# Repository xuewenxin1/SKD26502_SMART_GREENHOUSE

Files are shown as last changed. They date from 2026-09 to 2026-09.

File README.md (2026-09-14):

# SKD26502 大棚智能温湿度计和放风机

> **最近改了什么、主要在哪个文件夹？** 请看 [`修改说明_README.md`](修改说明_README.md)。

| 按键 | 作用 |
|---|---|
| **F7** | 编译并烧录放风机（`04.controller_unit_motor_freertos`） |
| **F8** | 编译并烧录温湿度计（`04.controller_unit_sensor_freertos`） |
| 终端任务 `Build All` | 两个固件都编译 |

烧录用 `pyocd`（驱动 ST-Link），芯片 `py32f071xb`。请先接好调试器再按 F7 或 F8。

产物在各自工程的 `build` 目录：`SKD26502_SMART_GREENHOUSE.hex` / `.bin` / `.elf`。

**电脑什么都没装时（只烧录，不编译）：**  
打开文件夹 **`烧录包`**（可整夹拷走），看里面的 `使用说明.txt`：  
1）第一次双击 `setup_flash_env.bat`  
2）插 ST-Link、板子上电  
3）双击 `flash_motor.bat`（烧 `SKD26502_motor.bin`）或 `flash_sensor.bat`（烧 `SKD26502_sensor.bin`）  

重新编译后，在烧录包里运行 `sync_bins_from_build.bat` 可更新这两个 bin。

日常开发编译仍需要：CMake、Ninja、Arm GNU Toolchain `arm-none-eabi-gcc`；烧录另需 ST-Link。

开机不主动转、不归零：按 Flash 里上次停稳的开度记住位置，电机保持不动，屏幕直接显示该开度。改 C1 行程圈数后仍会先关到 0%，不会自动再开回去。关到限位：电流为 0 并停住后断电、关灯灭。再按开时，开度会马上从 0% 往上走。首页短按设置键是暂停；开/关键在任意模式下都能用，暂停之后也可以再开再关。电机在转时对应的开/关灯亮；到 0% 关灯灭，到 100% 开灯灭，停下也灭。开到 100% 或关到 0% 后电机会停；这时直接按开或关即可，不用先按停。只有电机真正停住大约 0.5 秒后，才会把开度写进 Flash。转动过程中不记忆；中途断电不会记住跑到一半的位置，下次开机仍按上一次停稳的开度显示（也不主动去转）。发给小程序的开度联网成功后才会发。开机大约 10 秒后按原版方式连 4G：先 AT，再读 IMEI/SIM，再连 MQTT。连上后会按 `greenhouse/IMEI/up/dev` 上报设备信息：1 字节类型（放风机 1、温湿度计 2）、15 字节 IMEI、20 字节卡号、1 字节校验和。成功会打印 `Get IMEI OK`、`MQTT connect OK`、`Report device info`、`Report opening`。联网失败不会影响开关风机。

设置页 **C1** 为行程**圈数**（1～999），**C2** 为**一圈秒数**（10～100，默认 25）。满行程时间 = C1×C2（例如 C1=3、C2=25 → 约 75 秒）。自动校准按当前 C2 把测得秒数换算成圈数写入 C1。旧板若 C1 仍是秒数（大于 99），开机加载时会按 C2 换算成圈数。

电机电流为 0 并且已经停住时，如果开度只差一点点不到头，就当成到限位，显示改成 0% 或 100%。关到 0% 或开到 100% 后电机会停、开关灯会灭；这时直接按开或关即可，不用先按停。

设置页加减键：短按每次变 1，长按每次变 10（按住会连续跳）。开关类项目仍是切换。回差 P2 只能设 0、1、2、3、4、5℃，加减每次只变 1，出厂默认 0℃。S0 数据上报间隔可调 **5～30** 秒（默认 5），退出设置后写入 Flash。设置页 D1～D4、P0、P3 暂时隐藏；以后要显示时，把 `gui.cpp` 里的 `GUI_ENABLE_D1_D4_SETTING` / `GUI_ENABLE_P0_P3_SETTING` 改成 `1` 再编译。

按行程圈数×每圈秒数（C1×C2）开合；关窗不会因为电流抖动直接跳成 0%。

温湿度计首页不显示开度、百分号和 OK。BAT_C（PB15）一直拉高，ADC 基准 3.6V，电量按 1.8V=空、2.1V=满（约 2.08V 应接近满格）。请用 **F8** 烧录温湿度计。

自动模式：把工作模式调到自动。按设置页 **P5 上限 / P6 下限** 带回差控制（整数℃）：温度 **≥ P5** 时全开；温度 **≤ P6** 时全关；**P6～P5 之间保持原状**（升温未到上限不开，降温未到下限不关）。例如 P6=20、P5=25：早晨 18℃关着 → 升到 20～24℃仍关 → 到 25℃全开 → 再到 30℃仍开 → 回落到 25℃仍开 → 降到 20℃才全关。默认 P5=25、P6=20；温度可设 0～55℃，且上限必须比下限高至少 1℃。**A1/A2** 仍只用于超限蜂鸣报警。请按 **F7** 烧录放风机。

温度高于 A1 上限或低于 A2 下限时，PA12 输出约 4kHz 方波让蜂鸣器响；回到范围内就停。S2 本地报警关掉则不响。温度只看整数℃。**NTC 和温湿度计都不插、显示 `---` 时：同样蜂鸣并亮告警。** MQTT 状态帧故障码：`1` 电机过流，`2` 传感器故障（无有效温度），`3` 温度超限（超出 A1/A2）；优先级 1>2>3。放风机按 **F7**，温湿度计按 **F8**。

传感器选用：都插时温度用 NTC、湿度用温湿度计；只插温湿度计则用它的温湿度；只插 NTC 则只有温度、湿度不显示；都不插则温度湿度显示 `---` 并报警。NTC 温度按 **B 值法**计算（B=3950、R25=10kΩ、串联上拉 10kΩ）。**P4** 在实测温度上加减补偿（0.1℃ 步进），已作用于显示、报警、自动模式、MQTT。

电机自动校准：往返都按真实走到限位才停，不再因软件开度计时提前停；校准结束后才写入 C1 行程。App 强制开/关期间不做堵转停机；中途若已停住不再自动重试，保持当时开度。软件过流保护已关闭。用户停、软件开度到 0%/100%、电流≈0 限位仍会停。

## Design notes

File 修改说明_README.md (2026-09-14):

# SKD26502 近期修改说明

这份文档说明：**最近改了什么问题、主要在哪个文件夹、对应哪些源文件**。  
日常怎么烧录、怎么用机器，请看根目录的 [`README.md`](README.md)。

---

## 1. 主要改在哪个文件夹？

**日常开发只动下面两个固件工程**（FreeRTOS 版）：

| 文件夹 | 是什么 | 烧录按键 |
|---|---|---|
| `03.software/02.source_code/04.controller_unit_motor_freertos/` | **放风机** 固件 | **F7** |
| `03.software/02.source_code/04.controller_unit_sensor_freertos/` | **温湿度计** 固件 | **F8** |

辅助脚本：

| 路径 | 作用 |
|---|---|
| `scripts/build_firmware.ps1` | 编译 / 烧录脚本（F7、F8 会调用） |
| **`烧录包/`** | **整夹拷走即可烧录**：bin + bat（motor/sensor 已标识） |
| `烧录包/SKD26502_motor.bin` + `flash_motor.bat` | 放风机 |
| `烧录包/SKD26502_sensor.bin` + `flash_sensor.bat` | 温湿度计 |
| `烧录包/setup_flash_env.bat` | 首次安装便携烧录环境 |

下面这些是旧工程或资料，**一般不用改**：

- `01.controller_unit.old/`、`02.controller_unit_motor/`、`03.controller_unit_sensor/` → 旧代码
- `01.requirements_analysis_and_system_design/` → 需求和设计文档
- `02.hardware/` → 硬件原理图 / PCB

---

## 2. 每个工程里常改的子目录

两个固件结构差不多，改功能时主要看：

```
04.controller_unit_xxx_freertos/
├── app/
│   ├── env/                 ← 温度采样、蜂鸣器、电池（温湿度计）
│   ├── gui/                 ← 屏幕显示、设置菜单（A1/P1/P2…）
│   ├── ventilate_service/   ← 电机开合、自动模式开度
│   └── iot/                 ← MQTT 上报 / 下发配置
└── system/drivers/config/   ← 参数默认值、Flash 保存、范围限制
```

---

## 3. 最近改了哪些问题？（按功能）

### ① 自动模式：按 P5/P6 上下限回差开/关

**问题/需求：** 自动模式按用户设定的通风上下限控制；中间带回差，避免频繁开关。  
**规则：** 只算整数℃。用设置页 **P5 上限**、**P6 下限**（默认 25℃ / 20℃）：

| 实测温度 | 开度 |
|---|---|
| ≥ P5（如 ≥25℃） | 100% 全开 |
| ≤ P6（如 ≤20℃） | 0% 全关 |
| P6 < T < P5（如 21～24℃） | **保持原状**（升未到上限不开，降未到下限不关） |

**主要文件：**

- `app/ventilate_service/ventilate_service.cpp` → 函数 `opening_from_temp_limits`
- A1/A2 仍只作报警上下限；P5/P6 专管通风开合

两套固件都有同样逻辑。

---

### ①b 上电不归零、C1 圈数 + C2 秒/圈

**问题/需求：**
1. 上电不主动转、不找零；屏幕显示上次停稳开度。
2. **C1** 行程圈数（1～99）；**C2** 一圈多少秒（1～99，默认 25）。满行程 = C1×C2 秒。

**主要文件：**

- `app/ventilate_service/ventilate_service.cpp` → `init` 不再调用 `align`；行程用 `motor_stroke_time × motor_turn_seconds`
- `system/drivers/config/config.hpp` → `temp_vent_*`、`motor_turn_seconds`
- `app/gui/gui.cpp` → 设置项 P5/P6/C1/C2

---

### ② 回差 P2 / P3：只允许 0～5℃ 整数，默认 0

**问题/需求：** 开度已经跟温差绑定，回差作用变小，所以缩小范围，避免和开度曲线“抢活”。

- 只能设：0、1、2、3、4、5
- 加减每次只变 1（长按也不会跳 10）
- 新板出厂默认 0℃
- 旧板若 Flash 里还是 5，开机加载时会被限制到合法范围；也可手动改

**主要文件：**

- `app/gui/gui.cpp` → 设置页加减
- `system/drivers/config/config.cpp` → `clamp_hysteresis`、默认值
- `app/iot/iot_process.cpp` → 云端下发配置时也限制 0～5

---

### ③ 设置页暂时隐藏 D1～D4、P0、P3

**问题/需求：** 四段定时与 P0/P3 暂时不用，菜单里不要出现。

- D1～D4：`#define GUI_ENABLE_D1_D4_SETTING 0`
- P0、P3：`#define GUI_ENABLE_P0_P3_SETTING 0`
- 改成 `1` 再编译，就会重新显示

**主要文件：** `app/gui/gui.cpp`

---

### ③b S0 数据上报间隔 5～30 秒（写 Flash）

**问题/需求：** 设置页 S0 可调 5～30 秒，退出设置后写入 Flash；开机按保存值上报。

- **5～30**：每隔 N 秒整包上报（设备信息 + 状态 + 配置）
- 默认 **5** 秒；加载/保存时限制在 5～30

**主要文件：** `app/gui/gui.cpp`、`system/drivers/config/config.cpp`、`app/iot/iot_service.cpp`

---

### ④ 温度超报警上下限 → 蜂鸣器响（约 4kHz）

**问题/需求：** 温度高于 A1 或低于 A2 时蜂鸣器响。

- 引脚：**PA12**
- 方式：TIM14 定时翻转，输出约 **4kHz** 方波（这颗芯片 PA12 没有硬件 PWM 通道）
- **S2 本地报警**关掉则不响
- **放风机、温湿度计都保留蜂鸣器**

**主要文件：**

- `app/env/env.cpp` → `buzzer_pwm_init`、`update_temp_alarm`、`TIM14_IRQHandler`
- `app/gui/gui.cpp` → 超限时点亮告警符号

---

### ⑦ MQTT 状态故障码 2 / 3

**需求：** 状态上报带故障码：`2`=传感器故障，`3`=温度超限。

| 故障码 | 含义 | 判定 |
|---|---|---|
| 0 | 正常 | — |
| 1 | 电机过流 | 电机状态 `ERROR_OVC`（保留） |
| 2 | 传感器故障 | 无有效温度（显示 `---`） |
| 3 | 温度超限 | 有温度，且超出 A1/A2 |

优先级：**1 > 2 > 3**。写入 MQTT `up/status` 第 8 字节（`buffer[7]`）。

**主要文件：**

- `app/env/env.cpp` → `Env::get_error_code`
- `app/iot/iot_service.cpp` → `IOTService_up_status`

两套固件都已改。

---

### ⑤ 温湿度计电池显示（仅传感器工程）

**问题/需求：** 温湿度计首页显示电量格。

- BAT_C：**PB15** 一直拉高
- ADC：**PA4**，基准按 3.6V；约 1.8V=空、2.1V=满
- 首页不显示开度 / `%` / OK

**主要文件（只在 sensor 工程）：**

- `app/env/env.cpp`
- `app/gui/gui.cpp`
- `system/drivers/adc/adc.cpp`

---

### ⑥ 传感器插拔选用规则

| 插法 | 温度 | 湿度 |
|---|---|---|
| NTC + 温湿度计都插 | **NTC** | **温湿度计** |
| 只插温湿度计 | 温湿度计 | 温湿度计 |
| 只插 NTC | NTC | 无（屏幕 `--`） |
| 都不插 | 无（屏幕 `---`） | 无（屏幕 `---`）；**蜂鸣 + 亮告警** |

**主要文件：** `app/env/env.cpp`、`system/drivers/ntc/ntc_service.cpp`、`system/drivers/aht2415/aht2415.cpp`

NTC 已改为 **B 值法**（B=3950、25℃ 阻值 10kΩ、板上串联上拉 **10kΩ**）；NTC 分压供电 **3.86V**（ADC 比值法）。**电量 ADC 仍按 3.6V 基准**，未改。

**P4 温度补偿已生效**：在实测温度上加 P4（单位 0.1℃），影响显示、报警、自动开度、MQTT。

**电阻箱 10k 校准**：10k/10k 中点理论 raw≈2048。放风机/温湿度计均已做 **ADC 校准 + PCLK/4**（`adc/py32f071_hal_msp.c`），实测 raw≈2050，**已去掉** `NTC_ADC_GAIN`。温湿度计若漏配 ADC 时钟，NTC 会读失败，双插时仍显示 AHT 温度（看起来像“插 NTC 温度不变”）。

---

### ⑦ 校准电机提前停（已修）

**原因：** 校准反向时软件计时为 0 会立刻停；堵转检测也可能误停；反向段几乎量不到时间导致 C1 偏短。

**改法：** 校准模式 `set_calibrating(true)` —— 不按开度倒计时停、关闭堵转误停、往返都累计时间，仍靠电流≈0 判限位。

**主要文件：** `system/drivers/motor/motor.cpp`、`app/ventilate_service/ventilate_service.cpp`

---

### ⑧ App 下发「开」后中途停住（已修）

**原因：** 强制开窗时，堵转误判或中途电流≈0 会先让电机 IDLE；上层又把「中途停」当成放弃，开度停在半路。

**改法：**
- 强制开/关期间关闭堵转停机（`set_ignore_stall(true)`），减少中途误停
- 中途若已停住：**不再自动重试**，保持当前开度
- 仍靠开度到 100%/0%，或「电流≈0 + 开度已高/低」判到位

**仍会真正停住的情况：** 到 100%/0%、到位电流≈0、用户按停 / App 下发停、中途其它原因停住后保持开度（过流保护已关闭）

**主要文件：** 同上 `motor.cpp`、`ventilate_service.cpp`

---

### ⑨ 其它已落地的基础行为（两套工程）

| 内容 | 大致位置 |
|---|---|
| 开机不归零：保持上次开度，电机不动 | `ventilate_service` |
| 开度只在电机停稳约 0.5 秒后写入 Flash | `ventilate_service` |
| C1 圈数(1～999) + C2 秒/圈(10～100) | `gui` + `config` |
| 退出设置不覆盖 MQTT 下发的工作模式 | `gui` |
| MQTT config 含 C1/C2/P5/P6；status 报当前圈数（不×10） | `iot` |
| MQTT `up/dev`：放风机类型 1、温湿度计类型 2 | `iot` |

---

## 4. 对照表：功能 → 文件夹 → 文件

| 功能 | 主要文件夹 | 关键文件 |
|---|---|---|
| 自动开度按 P5/P6 上下限 | `.../app/ventilate_service/` | `ventilate_service.cpp` |
| 回差 0～5、默认 0 | `.../app/gui/` + `.../system/drivers/config/` | `gui.cpp`、`config.cpp` |
| 隐藏 D1～D4 / P0 / P3 | `.../app/gui/` | `gui.cpp`（`GUI_ENABLE_D1_D4_SETTING`、`GUI_ENABLE_P0_P3_SETTING`） |
| S0 上报间隔 5～30 写 Flash | `.../app/gui/` + `.../system/drivers/config/` + `.../app/iot/` | `gui.cpp`、`config.cpp`、`iot_service.cpp` |
| 蜂鸣器 4kHz | `.../app/env/` | `env.cpp` |
| 电池电量（仅温湿度计） | `.../app/env/` + `.../app/gui/` | `env.cpp`、`gui.cpp` |
| 传感器插拔选用 | `.../app/env/` + `.../system/drivers/ntc/` | `env.cpp`、`ntc_service.cpp` |
| MQTT 故障码 2/3 | `.../app/env/` + `.../app/iot/` | `env.cpp`、`iot_service.cpp` |
| NTC B 值测温 | `.../system/drivers/ntc/` | `ntc_service.cpp`（B=3950） |
| 校准提前停修复 | `.../system/drivers/motor/` + `.../app/ventilate_service/` | `motor.cpp`、`ventilate_service.cpp` |
| App强制开中途停 | `.../system/drivers/motor/` + `.../app/ventilate_service/` | `motor.cpp`、`ventilate_service.cpp` |
| 关闭软件过流保护 | `.../system/drivers/motor/` | `motor.cpp` |
| MQTT 配置钳位 | `.../app/iot/` | `iot_process.cpp` |
| 使用说明 / 烧录 | 项目根目录 | `README.md` |
| 本文（改动说明） | 项目根目录 | `修改说明_README.md` |

路径里的 `...` =  
`03.software/02.source_code/04.controller_unit_motor_freertos`  
或  
`03.software/02.source_code/04.controller_unit_sensor_freertos`

---

## 5. 烧录提醒

1. 改放风机相关 → 按 **F7**
2. 改温湿度计相关 → 按 **F8**
3. 两边都改了同一功能（如回差、蜂鸣器、自动开度）→ **F7 和 F8 都要烧一次**
4. 板子要先上电，再接调试器烧录

---

## 6. 以后可能继续改的方向

- 需要定时功能时：把 `GUI_ENABLE_D1_D4_SETTING` 改回 `1`
- 需要 P0/P3 时：把 `GUI_ENABLE_P0_P3_SETTING` 改回 `1`
- 蜂鸣器若要改频率：改 `env.cpp` 里的 `BUZZER_FREQ_HZ`（当前 4000）
- 自动开度上下限若要再调：改 `ventilate_service.cpp` 里的 `opening_from_temp_limits`

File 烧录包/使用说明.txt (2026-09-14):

================================================
  烧录包（整夹拷走就能用）
================================================

本文件夹里的文件：

  SKD26502_motor.bin     放风机固件（带 motor 标识）
  SKD26502_sensor.bin    温湿度计固件（带 sensor 标识）
  flash_motor.bat        烧放风机
  flash_sensor.bat       烧温湿度计
  setup_flash_env.bat    第一次用：装便携 Python + pyocd
  sync_bins_from_build.bat  从工程重新拷贝最新 bin（开发用）

用法：
  1. 第一次双击 setup_flash_env.bat（要联网）
  2. 插 ST-Link，板子上电
  3. 双击 flash_motor.bat 或 flash_sensor.bat

可以把整个「烧录包」文件夹拷到 U 盘 / 别的电脑使用。
================================================

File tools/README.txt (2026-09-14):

此目录由 setup_flash_env.bat 自动生成便携 Python / pyocd。
不要手工改。可随时删除整个 tools 文件夹后重新运行安装脚本。

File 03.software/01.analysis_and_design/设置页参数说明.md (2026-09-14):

# 放风机设置页参数说明

屏上代号显示在湿度数码管，数值显示在温度数码管。  
长按设置键进入设置页，短按设置键切换下一项。

对应固件：`04.controller_unit_motor_freertos`（`app/gui/gui.cpp`）。

## 全部参数

| 显示 | 含义 | 单位/取值 | 范围 | 说明 | 当前是否显示 |
|---|---|---|---|---|---|
| **a1** | 温度报警上限 | ℃ | 0～55，且 > a2 | 超温报警 | 是 |
| **a2** | 温度报警下限 | ℃ | 0～55，且 < a1 | 低温报警 | 是 |
| **p0** | 温控模式 | 1 / 2 | 1=中心温控，2=限值温控 | 切换自动温控算法 | **否**（`GUI_ENABLE_P0_P3_SETTING=0`） |
| **p1** | 目标中心温度 | ℃ | 0～55 | 中心温控用 | 是 |
| **p2** | 温度正回差 | ℃ | 0～5 | 升温侧回差 | 是 |
| **p3** | 温度负回差 | ℃ | 0～5 | 降温侧回差 | **否**（`GUI_ENABLE_P0_P3_SETTING=0`） |
| **p4** | 温度补偿 | ℃（0.1℃步进） | −9.0～+9.0 | 传感器修正，可显示负号 | 是 |
| **p5** | 开启温度上限 | ℃ | 0～55，且 > p6 | 自动模式：≥此温全开 | 是 |
| **p6** | 关闭温度下限 | ℃ | 0～55，且 < p5 | 自动模式：≤此温全关 | 是 |
| **d1** | 定时段1 | 时刻 + 开度% | 时 0～23；开度 0～100 | 定时模式第1段 | **否**（`GUI_ENABLE_D1_D4_SETTING=0`） |
| **d2** | 定时段2 | 同上 | 同上 | 定时模式第2段 | **否** |
| **d3** | 定时段3 | 同上 | 同上 | 定时模式第3段 | **否** |
| **d4** | 定时段4 | 同上 | 同上 | 定时模式第4段 | **否** |
| **c1** | 电机行程总圈数 | 圈 | 1～999 | 满行程圈数；精确下发最大圈数即为此值；校准可写入 | 是 |
| **c2** | 一圈时间 | 秒/圈 | 5～100 | 目标时间 ≈ 圈数 × c2 | 是 |
| **s0** | 数据上报间隔 | 分钟 | 5～30 | MQTT 周期上报 | 是 |
| **s2** | 本地报警开关 | 0 / 1 | 0=关，1=开 | 蜂鸣等本地报警 | 是 |

## 当前机上可翻到的顺序

```
a1 → a2 → p1 → p2 → p4 → p5 → p6 → c1 → c2 → s0 → s2
```

（p0、p3、d1～d4 被宏关掉，切换时自动跳过）

## 相关计算

- 满行程时间 ≈ **c1 × c2** 秒  
- 精确下发 N 圈的目标时间 ≈ **N × c2** 秒  
- 断电保存的行程计时按**整秒**落盘  

## 开关宏（gui.cpp）

| 宏 | 默认 | 作用 |
|----|---|---|
| `GUI_ENABLE_D1_D4_SETTING` | 0 | 1=显示 d1～d4 |
| `GUI_ENABLE_P0_P3_SETTING` | 0 | 1=显示 p0、p3 |

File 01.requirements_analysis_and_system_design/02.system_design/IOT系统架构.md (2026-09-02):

# IOT系统架构

## 1. 整体架构

IOT系统包含三大部分，分别是云端后台、前端和设备端。其中前端可以小程序、APP、Web的形式实现。

### 1.1 云端后台

云端后台是整个IOT系统的中枢，负责消息路由，设备/用户管理，业务逻辑。云端后台采用微服务架构进行实现。后端由MQTT Brober (采用EMQX实现)，用户管理与鉴权服务，业务逻辑服务三部分组成。

#### 1.1.1 MQTT Broker

MQTT Broker负责支持MQTT协议通信，采用发布/订阅模型。该服务主要负责对于MQTT消息的路由。

#### 1.1.2 用户管理与鉴权服务

该服务面向MQTT Broker，通过HTTP端口向MQTT Broker提供用户认证，鉴权的接口。负责管理哪些设备可以接入，接入的设备可以订阅/发布哪些主题。

#### 1.1.3 业务逻辑服务

业务逻辑服务负责订阅相关的消息，如温度等，并自动判断是否需要执行某些自动化操作，如温度过高自动发布打开换气的消息。
   
### 1.2 前端

前端主要负责对设备信息进行展示，提供手动控制的方法，并支持对设备进行配对操作。前端通过HTTP协议接入用户管理与鉴权服务，并通过MQTT协议接入IOT消息路由。

### 1.3 设备端

设备端指IOT设备，通常以传感器、执行器的形式实现。设备端负责对IOT场景进行感知和控制。设备端通过MQTT协议接入IOT消息路由。

## 2. 产品与设备抽象

每一类产品都是一类数据与服务的集合，系统通过类目(product)来区分某一类产品。同类目的产品将使用同样的业务逻辑。产品类目使用类目id(product id,pid)进行唯一标识。
在系统使用时，我们认为每一个设备都只能绑定某一个组(group)，每一个组都通过组id(group id, gid)进行唯一标识，而每一个设备都会在其配网时分配一个虚拟的设备id(virtual id, vid),该id用于在IOT系统中唯一确定一个设备，此外还会在配网时为其分配一个登录凭据(device token)，该token是长效token，用于作为MQTT认证的凭据。每一个设备都具有多个属性和动作，我们将属性和动作统一抽象为数据点(data point, dp)。
每一个设备所使用的主题都遵循如下命名规则。

`{pid}/{vid}/{dir}/{dp}`

其中dir标识数据流向，up代表上行，即设备到服务器，down代表下行，即服务器到设备。

针对每一个类目，都将会在系统中注册dp list。该dp list决定了拥有对应pid的产品以及具有访问权限的用户可以订阅/发布关于该pid的哪些主题。

## 3. 用户管理

每一个用户都具有一个唯一标识(user id, uid), 每一个用户可以加入多个组。每一个用户可以管理其组内的设备。

每一个用户都具有一组(uid, token)作为用户认证凭据。用户登录根据不同的前端实现形式可以采用账密/微信认证接口等不同的方式实现，用户通过对应的方式进行登录后将会拿到token,该token会作为MQTT认证的凭据。

## 4. 其他

如果前端系统以Web形式实现，还需要在后端实现用以支持页面显示的Web服务器。

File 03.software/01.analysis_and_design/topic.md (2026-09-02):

# 大棚主题

# 上报主题

主题：greenhouse/vid/up/status
内容格式：

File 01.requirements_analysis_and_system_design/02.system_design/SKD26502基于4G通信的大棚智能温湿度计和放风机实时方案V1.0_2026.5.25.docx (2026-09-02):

基于4G通信的大棚智能温湿度计和放风机

Intelligent greenhouse temperature & humidity meter and ventilator based on 4G communication
项目名称Project Name： | 基于4G通信的大棚智能温湿度计和放风机
项目编号Project No.： | /
产品名称Product Name： | 基于4G通信的大棚智能温湿度计和放风机
产品型号Product Model： | /
产品专用号Part Number： | /
发布日期 Release Date： | 2026.2.27

# 1 项目概述

## 1.1应用场景和功能需求

产品为智慧农业场景下的职能温湿度计和带温控功能的放风机。使用4G进行远程通信，并用小程序远程控制设备动作和监控大棚温度信息。具备报警提示功能。

## 1.2 功能项

从电控角度，建议如下方式规划产品版本

序号 | 版本 | 主要功能配置 | 备注
1 | 温湿度计 | ①同时支持温湿度传感器和NTC温度传感器监测，并优先识别温湿度传感器 ②支持雨雪监测，主要实现是否雨雪天气，不关注雨雪的大小 ③可以设定报警温度上下限 ④支持本地温湿度显示、报警，可以设定传感器数据上报时间间隔 ⑤支持通过服务器给用户发短信、打电话 ⑥支持查看故障报警记录、温度曲线 ⑦使用LCD液晶屏，显示网络通信状态、设备SN、时间信息
2 | 放风机 | ①同时支持温湿度传感器和NTC温度传感器监测，并优先识别温湿度传感器 ②支持雨雪监测，主要实现是否雨雪天气，不关注雨雪的大小 ③可以设定报警温度上下限 ④支持本地温湿度显示、报警，可以设定传感器数据上报时间间隔 ⑤支持通过服务器给用户发短信、打电话 ⑥支持查看故障报警记录、温度曲线 ⑦本地和小程序控制放风机动作，得到开度信息 ⑧电机行程时间校准，包括自动校准和手动快速输入行程时间 ⑨运行模式分为自动模式、手动模式、定时模式等 ⑩自动模式跟温度绑定，自动调整开度。

# 2 硬件方案

## 2.1LCD屏幕内容

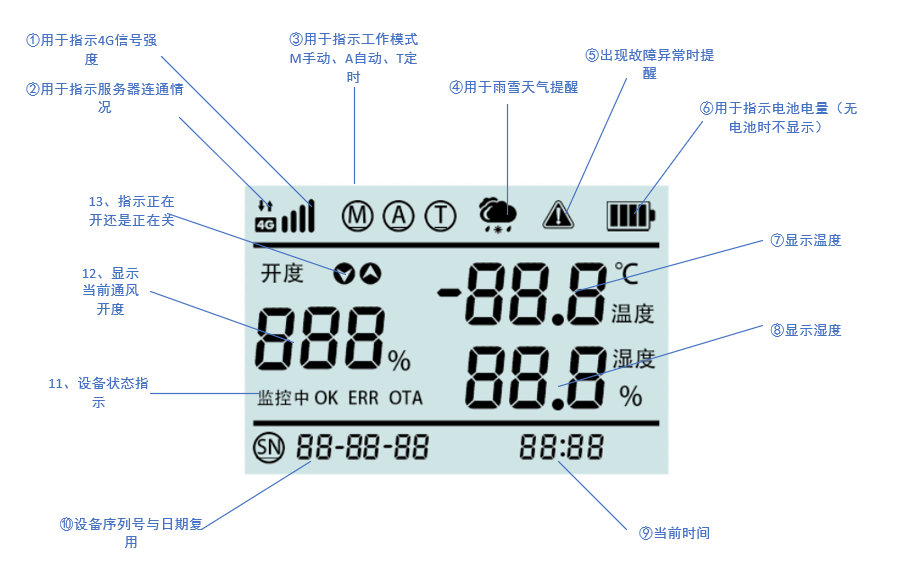
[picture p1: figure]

### 2.1.1屏幕尺寸与光学说明

可视区域尺寸：长约46mm宽32mm，总尺寸屏幕厂家根据工艺确定。

视角：12点钟

驱动：1/4duty，1/3bias

工作电压：3.0V

类型：TN 正显

温度：工作温度-20℃~+70℃，存储温度-30℃~+80℃

频率：64Hz

引脚：排针Pin脚

2.1.2屏幕内容

①，用于指4G信号传输和信号强度。其中上下箭头为一段，总一起动。4G及周五的黑框为一段，4个信号强度的竖线分别为4段。

②用于指示三种工作模式，每个圈及圈内内容构成的图案为一个段，总共3个段。

③用于指示天气是否有雨雪。该图标整个为一个段。

④告警提示图标，站一个段。

⑤用于指示电池电量。其中电池外框与左侧第一个格子共同组成1段，其余3个格子各占一个段，总共4段。

⑥两个分割线，用于装饰显示内容，分别各占一个段。

⑦温度显示区，其中“温度”与℃单位共用一个段，总是同时亮灭。其余8字，各占7段，负号和小数点各占一段。总共24段。

⑧湿度显示区，和上条类似，但是没有负号，总共23段。

⑨防风机开度显示区，其中“开度”、上箭头、下箭头、百分号分别占用一个段，每个8字占7个段。总共25段。若电机处于正在开则上箭头闪烁，处于正在关则下箭头闪烁，处于暂停则上下箭头隐藏。处于校准过程中，则三个8字的外圈段按先后滚动显示。呈现一个在循环和运行的状态。

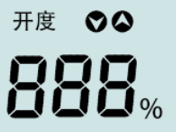
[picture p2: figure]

⑩为设备运行状态指示区，“监控中”“OK“ERR”“OTA”分别占一个段，总共4段。

⑪每个8字占7段，SN及圆圈内内容占一段，8字之间的端横和冒号，各占一个段。此区域总共74段。

## 2.2按键与交互

产品有4个功能按键，分别为模式、设置、减按键、加按键。

设置和确认按键：

①短按模式按键，可以在自动、手动、定时三个工作模式之间切换；

②长按设置按键3秒，可以进入详细参数设置菜单。进入菜单后，每短按一下则切换一个设置参数项目。此时湿度处段码显示参数代号，温度处显示当前设置的参数。通过减按键、加按键实现参数的调整。参数一览表如下：

参数代号 | 参数功能描述 | 可设置范围 | 步进 | 默认值
A1 | 报警温度上限 | 0℃~55℃ | 1℃ | 45℃
A2 | 报警温度下限 | 0℃~55℃ | 1℃ | 10℃
P0 | 放风机的温控模式 | 1中心温度+回差模式 2温度上下限模式 | 1 | 2
P1 | 中心适宜目标温度 | 0℃~55℃ | 1℃ | 25℃
P2 | 控温正回差 | 1-15℃ | 1℃ | 5℃
P3 | 控温负回差 | 1-15℃ | 1℃ | 5℃
P4 | 温度校准 | ±~10.0摄氏度 | 0.1℃ | 0.0℃
d 1 | 第一段定时时间及开度设置 | 时间为0-23，开度为0-100% | 1 | 9点，50%
d 2 | 第一段定时时间及开度设置 | 时间为0-23，开度为0-100% | 1 | 11点，100%
d 3 | 第一段定时时间及开度设置 | 时间为0-23，开度为0-100% | 1 | 16点，50%
d 4 | 第一段定时时间及开度设置 | 时间为0-23，开度为0-100% | 1 | 17点：0%
C1 | 电机行程时间 | 0-999 | 1 | 30
S0 | 数据上报时间间隔 | 0-30 | 1 | 5
S2 | 本地报警开关 | ON/OFF | 1 | 开

③别的，当设置到d1-d4参数项目时，屏幕底部的时间点显示。此时按“模式”按键，可以切换时间和开度之间进行切换，正设置的参数闪烁，设置完或者未设置的参数常亮。减按键、加按键每按一下可以改变参数数值。当持续按住按加减可以快速修改参数数值。

④参数修改后完成后，5s没有进一步操作，则参数生效。在设置菜单下，如果30s没有进一步操作，则退出设置菜单，回到主界面。

⑤长按设置按键秒也可以回到主界面。只要退出设置菜单，则用户的修改均立即生效。

*注意，需要温度上限应始终大于等于温度下限，放置逻辑混乱。

⑥同时长按加减键可以重置设备，使设备恢复出厂设置。

## 2.3本地控制框图与说明

2.3.1板外输入输出

2.3.2板上控制拓扑

2.3.3使用低成本的PY32F030/F031作为主控芯片；

2.3.4使用基于中移的307C-DL作为通信模组，与单片机之间通过串口连接，通过AT指令传递命令和建立远程通信；

2.3.5使用TM1750（低成本）驱动LCD液晶屏，驱动芯片与单片机IIC通信；

2.3.6使用AHT2415C作为高级的的温湿度传感器，与单片机IIC通信。

2.3.7系统兼容NTC传感器和基于模拟量的雨水检测传感器。特别的，雨水检测传感器预留位UART接口或者可以复用的其他接口，以便于后期拓展不同传感器类型。预留一路MOS输出的PTC加入器接口，用于应对雪天无法监测的特殊情况。PTC功率不超过3W。

2.3.8设备使用3个继电器来实现电机换向控制。

2.3.9预留RTC外围电路，以保证设备时间准确。

## 2.4设备电源拓扑

2.4.1设备考虑两种可选的供电方式，分别是直接接DC24V与直接接AC220V。变更输入电源的时候，同时变更对应的执行电机。24V和220V不同时存在。

2.4.2设备使用5V继电器，无论何种电源，均线转换到5V，然后经过小功率DC/DC或者LDO给系统控制芯片、模块供电。

2.4.3其中4G模块应保证2A的最大工作电流。

2.4.4 4G模块与单片机IO之间做电平转换。

## 2.5负载、传感器与配件

序号 | 配件名称 | 规格型号 | 备注
1 | 温度传感器 | 10K NTC 3950K_10K3950R1130926
2 | 温湿度传感器 | AHT2415C
3 | 直流减速电机 | 24V 4A 100W 自带限位开关，到达限位后电流为0

# 3软件功能

## 3.1控制板软件逻辑

## 除了实现上文2.1和2.2的内容外显示和按键功能外，应实现温湿度采集、放风机控制。

### 3.1.1温湿度检测与优先级

①设备自动检测传感器类型。并优先使用IIC温湿度传感器的数据。设备上电以后先建立和AHT2415C的通信，获取温湿度数据，如果AHT2415C温湿度数据获取失败，则检测NTC的数值，如果获取成功，则显示NTC计算出的温度值，湿度值显示“- - -”或者隐藏不显示。若也无法获取NTC的数值，或者检测到NTC短路短线，则报传感器故障的错误。只要有错误，则屏幕“ERR”闪烁，同时温湿度数据都显“- - -”，用于提示是传感器方面的错误。

②温湿度数据上报。设备刚上电检测到数据后先上报一次温湿度。此后每5分钟上报一次温湿度数据以节省4G流量。本地按照温度情况实时显示温度变化。小程序上应具备一个“立即刷新数据”的功能供用户操作。

### 3.1.2雨雪监测

通过雨雪监测模块的电平变化判断当前降水情况。核心原理为触点短路与比较器信号输出。当监测到有雨雪则让屏幕上雨雪图标常亮。没有雨雪则图标熄灭。

### 3.1.3放风机开度行程校准、监测

设备通过采样电阻采集电机绕组电流，并依据电流情况判断电机是否在运行或者堵转过载。

①电流信号转化为ADC电压信息，若连续3次监测到电机电流≥4A，则认为电机过载。此时应该电机停机，并触发报警。

②若监测到电机电流大于0且小于4A，则认为电机当前在正常运行。

③依据电路特点，电流只有继电器动作后才产生，引出执行换向或者暂停电机工作电流为0。依据电机特性，电机到达物理行程以后，电流也变变成0。

④自动校准：电机安装完成以后，通过本地按键进入设置功能。长按“模式”按键3s可以，此时用户电机模式后电机进入自动校准过程。

Step1：电机顺时针旋转知道监测到电流为0，确保电机运行到起始位置；

Step2：电机逆时针时针旋转，并开始计时，直到再次监测到电流为0，说明电机运行到另一极限，此时停止计时，得到行程时间T1；

Step3：电机再次顺时针旋转，走到极限得到行程时间T2；

Step4：有效行程时间为（T1+T2）/2。

注意：由于是继电器控制设备，存在时间误差，且电流的获取在继电器动作之后，应补充误差的时间。

④手动校准：进入设置菜单，参数为C1，此时开度显示，温湿度不显示，此时开度值为秒数。

若开发中发现需要用小数1位，则考虑使用温度显示的内容作为描述。温度的单位、汉字等不相干内容不显示。用户通过加减键调整时间行程。默认为30秒。

### 3.1.4放风机控制

放风控制支持3种模式分别是自动模式、手动模式、定时模式。

①用户通过“模式”按键切换当前设备放风机的工作模式。

②手动模式：在主页面下，用户可以直接通过按键加/键调整控制放风的开度。按一下加，则控制电机顺时针转动，电机转动起来以后按一下“设置”则可以停止电机运动；按一下减，则控制电机逆时针转动，电机转动起来以后按一下“设置”则可以停止电机运动。若用户按完加后又按减键，则电机先停止运动（暂定1秒，确保继电器完吸合/释放），然后向反方向运动。若用户按完减后又按加，同理。相同按键重复按则总是按照最新操作响应。通过按键操作防风机打开或者关闭以后，如果用户没有操作“暂停”则电机总是运行到最大行程时间后停止。

③定时模式：用户通过小程序或者本地设置定时时间和开度。定时总共在用户设定的4个定时中循环工作。最多支持4个定时，如果用户只设定了两个定时，则只在两个定时中循环。无效的定时在本地显示“----”，即相应的时间点和开度设置无效。

④自动模式：将温度与放风机开度绑定。如果大棚温度高于目标温度+正会差，则全开；如果大棚温度低目标温度-负回差，则全关。中间按照线性比例分8个挡位。

3.1.5故障类型及说明

序号 | 故障描述 | 本地 | 小程序 | 短信/电话通知
1 | 传感器故障（温湿度、温度） | ERR常亮 | 弹窗或者提示 | 有
2 | 电机过载 | ERR闪烁 | 弹窗或者提示 | 有
3 | 温度超过设定上下限 | 常亮 | 弹窗或者提示 | 有
4 | 4G模块无法通信 | ERR常亮 4G图标闪烁 | / | /

3.1.6上报的数据

序号 | 参数名称 | 数值范围 | 数据类型 | 上报下发
1 | 实时温度 | -30~80°C | 数值 | 仅上报（5min/次）
2 | 实时湿度 | 0~100% | 数值 | 仅上报（5min/次）
| 实时温湿度数据上报频率 | 0-30 | 数值 | 发生变化时上报下发
| 报警温度上限 | 0~100% | 数值 | 发生变化时上报下发
| 报警湿度下限 | 0~100% | 数值 | 发生变化时上报下发
| 湿度报警是否生效 | 是/否 | 布尔 | 下发
3 | 报警温度上限 | -30~80°C | 数值 | 发生变化时上报下发
4 | 报警温度下限 | -30~80°C | 数值 | 发生变化时上报下发
| 温度报警是否生效 | 是/否 | 布尔 | 下发
5 | 中心适宜目标温度 | -30~80°C | 数值 | 发生变化时上报下发
6 | 控温正回差 | 1~15℃ | 数值 | 发生变化时上报下发
7 | 控温正回差 | 1~15℃ | 数值 | 发生变化时上报下发
8 | 定时与开度 | 时间信息+开度 | 透传或者数值 | 发生变化时上报下发
9 | 电机行程时间 | 0-999 | 数值 | 发生变化时上报下发
10 | 设备工作模式 | 自动、手动、定时 | 枚举 | 发生变化时上报下发
11 | 电机运行状态 | 校准中、暂停中、打开中、关闭中 | 枚举 | 发生变化时上报下发
12 | 当前开度信息 | 0~100% | 数值型 | 本地实时显示，平台10s上传一次
13 | 电池充电状态 | 充电中、充电完成、未充电 | 枚举 | 发生变化时上报下发
14 | 电池电量 | 0~100% | 数值 | 仅上报（5min/次）
15 | 位置信息 | 位置数据 | 透传 | 仅上报

## 3.2小程序功能模块

参考已经样式，小程序功能模块应该包括如下几个部分：

### 3.2.1用户登录与注册模块

### 3.2.2设备添加与设备管理模块

①添加

②删除/解绑

3.2.3设备信息及设备控制监视模块

①设备传感器数据，温湿度历史曲线。（最长三个月）（平均温度计算）

②设备运行状态

③设备故障信息

④设备控制模块：开关、暂停、定时、校准、设置温湿度范围等，支持报警记录查看。

⑤报警管理：短信、电话、微信、本地报警控制开关。

⑥设置接收信息和电话的手机号。

⑦设备使用指南

3.2.4分享与设置

## 3.3小程序UI风格

## 3.2服务器功能与技术路线

编辑修改 审 核 批 准 Perry Jiang 编辑日期 审核日期 批准日期 2026.5.25 发布：2026年5月25日 1 / 10版本：V1.1.0

编辑修改 审 核 批 准 Perry Jiang 编辑日期 审核日期 批准日期 发布：2025年09月18日 1 / 14版本：V1.0.0

附件1：电控方案 项目名称 基于4G通信的大棚智能温湿度计和放风机 项目号 SKD26502 产品名称 基于4G通信的大棚智能温湿度计和放风机 产品专用号 / 产品型号 / 文档类型 方案_SO

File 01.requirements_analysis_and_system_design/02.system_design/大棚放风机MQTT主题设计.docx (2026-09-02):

# 智能大棚MQTT主题设计

## IOT相关数据

数据 | 类型 | 方向 | 描述
VID | 字符串 | 仅上报 | 用于唯一标识设备
ICCID | 字符串 | 仅上报 | USIM卡ID号码
开度 | 数值 | 可上报可下发 | 用于描述放风机的开度
模式 | 数值 | 可上报可下发 | 用于描述当前工作模式
温度 | 数值 | 仅上报 | 当前温度
湿度 | 数值 | 仅上报 | 当前湿度
温度报警上限 | 数值 | 可上报可下发 | 温度报警上限
温度报警下限 | 数值 | 可上报可下发 | 温度报警下限
目标温度 | 数值 | 可上报可下发 | 目标温度
温度正回差 | 数值 | 可上报可下发 | 温度正回差
温度负回差 | 数值 | 可上报可下发 | 温度负回差
传感器补偿值 | 数值 | 可上报可下发 | 传感器补偿值

## 主题列表

主题 | 描述
greenhouse/vid/up/dev | 用于上报设备基本信息，如VID，ICCID
greenhouse/vid/up/status | 上报设备状态，如温度，湿度，开度等
greenhouse/vid/up/config | 上报设备配置
greenhouse/vid/down/config | 下发设备配置
greenhouse/vid/down/act | 设备执行命令

## MQTT负载

负载为字节序列

主题:greenhouse/vid/up/dev

字段 | 长度 | 描述 | 实例
TYPE | 1Byte | 设备类型 1: 放风机 2: 传感器 | 01
VID | 15Byte | 设备IMEI号，作为VID | 869773089925004
ICCID | 20Byte | 卡号 | 898607B11824D0018581
Checksum | 1Byte | 校验和 | 0x00

主题:greenhouse/vid/up/status

字段 | 长度 | 描述 | 实例
温度 | 2Byte | 温度乘10（如123代表12.3度） | 123
湿度 | 2Byte | 湿度乘10 | 500
开度 | 2Byte | 开度乘10（如500代表50.0%） | 500
电机运行状态 | 1Byte | 0: 停止 1: 正在开启 2: 正在关闭 | 0
故障码 | 1Byte | 0: 无故障 1: 电机过流 | 0
Checksum | 1Byte | 校验和 | 0x00

主题:

greenhouse/vid/up/config

greenhouse/vid/down/config

字段 | 长度 | 描述 | 实例
模式 | 1Byte | 1:手动 2:自动 3:定时 | 1
温度报警上限 | 2Byte | 温度报警上限乘10 | 500
温度报警下限 | 2Byte | 温度报警下限乘10 | 500
目标温度 | 2Byte | 目标温度乘10 | 250
温度正回差 | 2Byte | 温度正回差乘10 | 50
温度负回差 | 2Byte | 温度负回差乘10 | 50
传感器补偿值 | 2Byte | 传感器补偿值乘10 | 20
设备可用 | 1Byte | 0: 设备不可用 1: 设备可用 | 1
Checksum | 1Byte | 校验和 | 0x00

主题:greenhouse/vid/down/act

字段 | 长度 | 描述 | 实例
动作类型 | 1Byte | 0:停止动作 1:设置开度到指定位置 2:手动开启 3:手动关闭 4:请求上报状态 5:请求上报配置 | 0
参数1 | 2Byte | 在动作类型为1时代表要设置的开度乘10 | 500
Checksum | 1Byte | 校验和 | 0x00

主题:greenhouse/vid/down/extra

字段 | 长度 | 描述 | 实例
时间-年 | 1Byte | 年份的低两位十进制，如2026取26 | 26
时间-月 | 1Byte | 月份的十进制 | 01
时间-日 | 1Byte | 日期的十进制 | 01
时间-小时 | 1Byte | 小时的十进制,24小时制 | 01
时间-分钟 | 1Byte | 分钟的十进制 | 01
显示的配网ID号 | 6Byte | 六位10进制数字，BCD码 | 0x01,0x02,0x03,0x04,0x05,0x06
Checksum | 1Byte | 校验和 | 0x00

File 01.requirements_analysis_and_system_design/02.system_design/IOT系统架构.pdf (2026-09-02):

# IOT系统架构

## 1. 整体架构

IOT系统包含三大部分，分别是云端后台、前端和设备端。其中前端可以小程序、APP、Web的形式实现。

### 1.1 云端后台

云端后台是整个IOT系统的中枢，负责消息路由，设备/用户管理，业务逻辑。云端后台采用微服务架构进行实 现。后端由MQTT Brober (采用EMQX实现)，用户管理与鉴权服务，业务逻辑服务三部分组成。

1.1.1 MQTT Broker

MQTT Broker负责支持MQTT协议通信，采用发布/订阅模型。该服务主要负责对于MQTT消息的路由。

1.1.2 用户管理与鉴权服务

该服务面向MQTT Broker，通过HTTP端口向MQTT Broker提供用户认证，鉴权的接口。负责管理哪些设备可以 接入，接入的设备可以订阅/发布哪些主题。

1.1.3 业务逻辑服务

业务逻辑服务负责订阅相关的消息，如温度等，并自动判断是否需要执行某些自动化操作，如温度过高自动发 布打开换气的消息。

### 1.2 前端

前端主要负责对设备信息进行展示，提供手动控制的方法，并支持对设备进行配对操作。前端通过HTTP协议接 入用户管理与鉴权服务，并通过MQTT协议接入IOT消息路由。

### 1.3 设备端

设备端指IOT设备，通常以传感器、执行器的形式实现。设备端负责对IOT场景进行感知和控制。设备端通过 MQTT协议接入IOT消息路由。

## 2. 产品与设备抽象

每一类产品都是一类数据与服务的集合，系统通过类目(product)来区分某一类产品。同类目的产品将使用同样 的业务逻辑。产品类目使用类目id(product id,pid)进行唯一标识。 在系统使用时，我们认为每一个设备都只能 绑定某一个组(group)，每一个组都通过组id(group id, gid)进行唯一标识，而每一个设备都会在其配网时分配一 个虚拟的设备id(virtual id, vid),该id用于在IOT系统中唯一确定一个设备，此外还会在配网时为其分配一个登录 凭据(device token)，该token是长效token，用于作为MQTT认证的凭据。每一个设备都具有多个属性和动作， 我们将属性和动作统一抽象为数据点(data point, dp)。 每一个设备所使用的主题都遵循如下命名规则。

{pid}/{vid}/{dir}/{dp}

其中dir标识数据流向，up代表上行，即设备到服务器，down代表下行，即服务器到设备。

IOT系统架构.md | 2026-05-27

1 / 2

针对每一个类目，都将会在系统中注册dp list。该dp list决定了拥有对应pid的产品以及具有访问权限的用户可 以订阅/发布关于该pid的哪些主题。

## 3. 用户管理

每一个用户都具有一个唯一标识(user id, uid), 每一个用户可以加入多个组。每一个用户可以管理其组内的设 备。

每一个用户都具有一组(uid, token)作为用户认证凭据。用户登录根据不同的前端实现形式可以采用账密/微信认 证接口等不同的方式实现，用户通过对应的方式进行登录后将会拿到token,该token会作为MQTT认证的凭据。

## 4. 其他

如果前端系统以Web形式实现，还需要在后端实现用以支持页面显示的Web服务器。

IOT系统架构.md | 2026-05-27

2 / 2

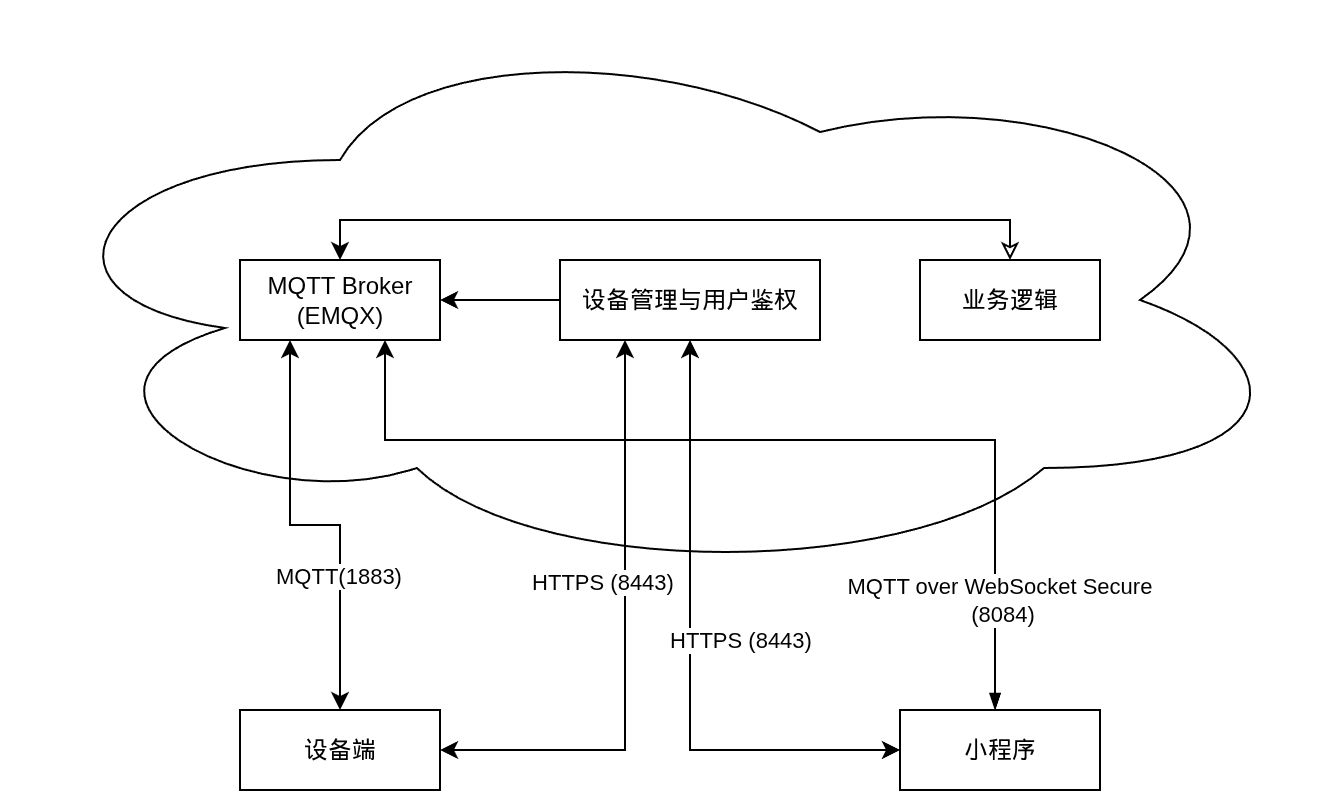
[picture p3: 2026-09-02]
01.requirements_analysis_and_system_design/02.system_design/系统架构图.png

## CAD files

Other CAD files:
02.hardware/02.pcb_design/JLW-T15606PW.dwg

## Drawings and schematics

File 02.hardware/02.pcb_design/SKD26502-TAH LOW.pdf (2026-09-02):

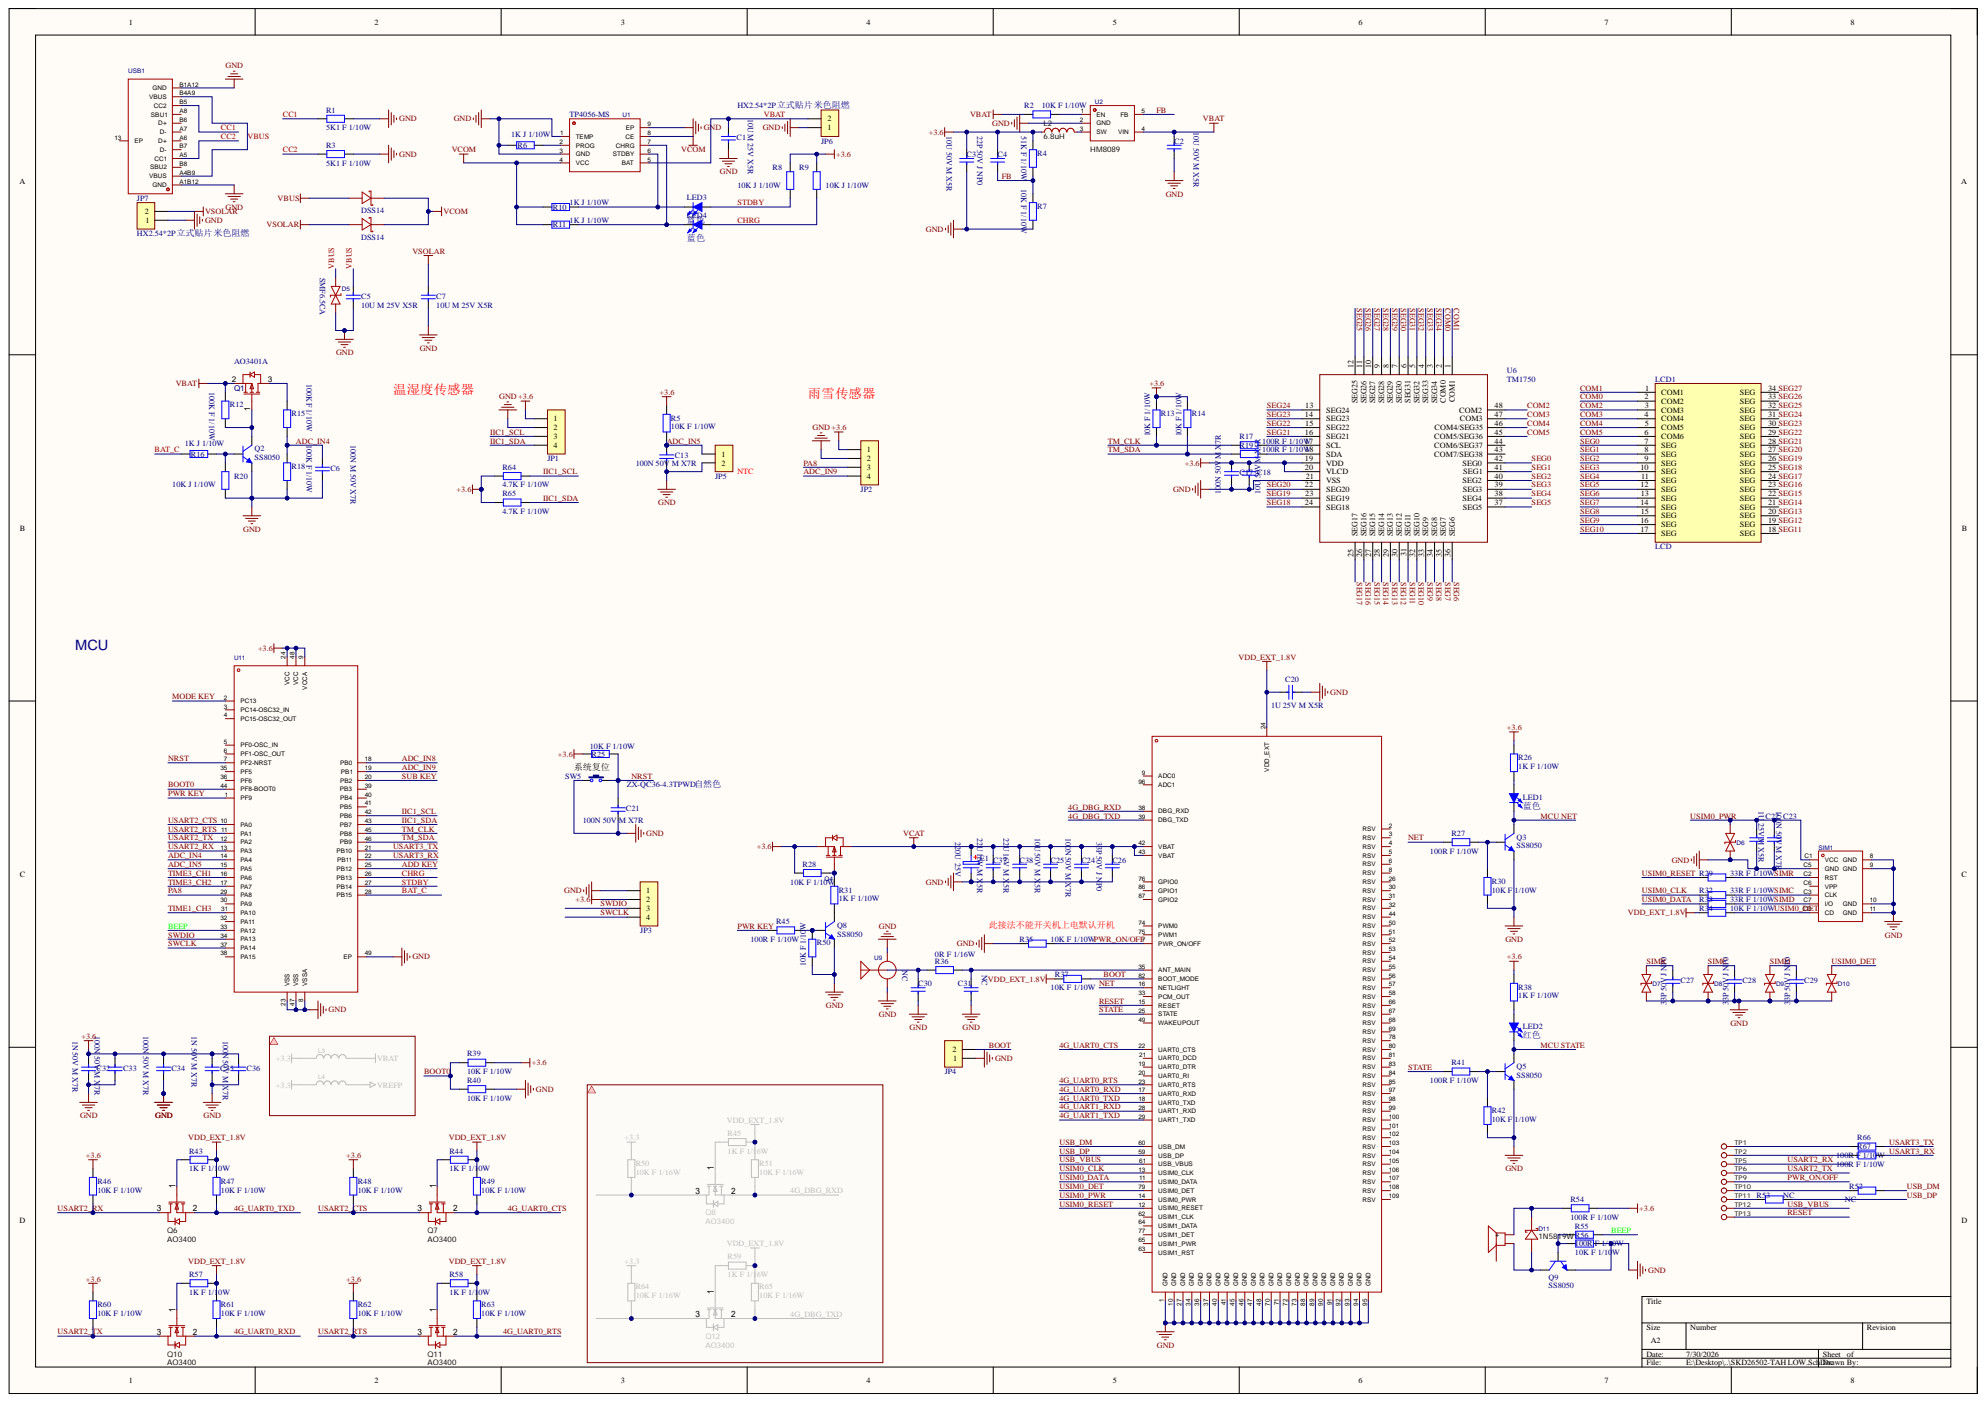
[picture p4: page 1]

VSSA 8 VCCA 9 VCC 48 VCC 24

GND 95 GND 94 GND 93 GND 92 GND 91 GND 90 GND 89 GND 88 GND 73 GND 72 GND 71 GND 70 GND 48 GND 47 GND 46 GND 45 GND 41 GND 40 GND 37 GND 36 GND 34 GND 27 GND 10 GND 1

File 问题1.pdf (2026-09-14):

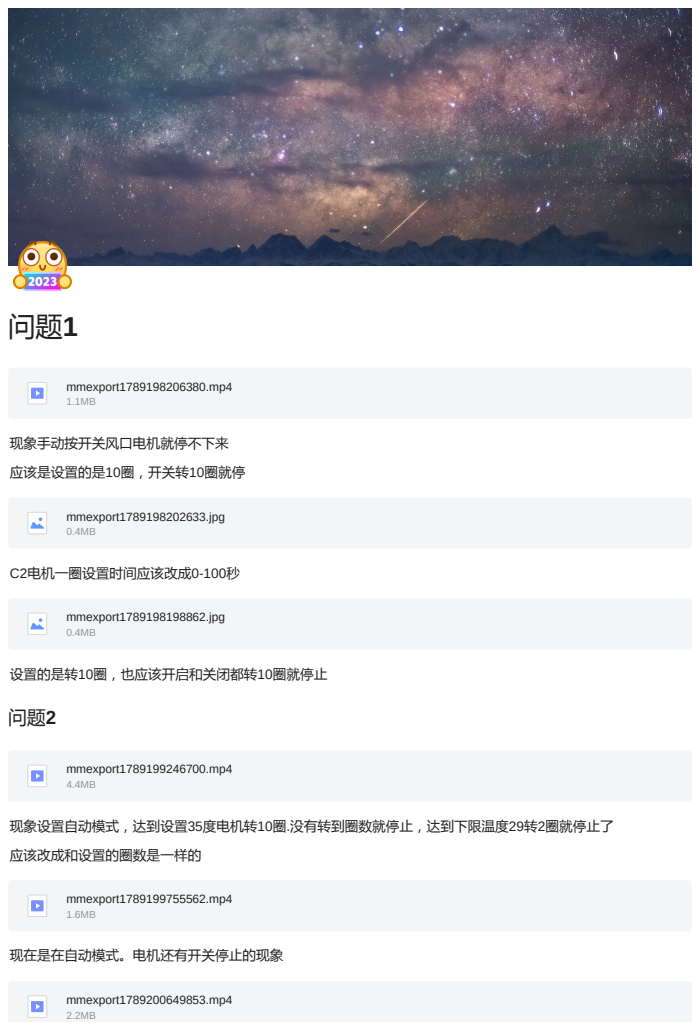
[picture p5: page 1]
mmexport1789198206380.mp4 1.1MB; 现象手动按开关风口电机就停不下来; 应该是设置的是10圈，开关转10圈就停; mmexport1789198202633.jpg 0.4MB; C2电机一圈设置时间应该改成0-100秒; mmexport1789198198862.jpg 0.4MB; 设置的是转10圈，也应该开启和关闭都转10圈就停止; mmexport1789199246700.mp4 4.4MB; 现象设置自动模式，达到设置35度电机转10圈.没有转到圈数就停止，达到下限温度29转2圈就停止了; 应该改成和设置的圈数是一样的; mmexport1789199755562.mp4 1.6MB; 现在是在自动模式。电机还有开关停止的现象; mmexport1789200649853.mp4 2.2MB

## 定时模式开启关闭风口和设置的圈数不一致

## 现在离线就解绑不了设备了，应该改成离线也能解绑设备

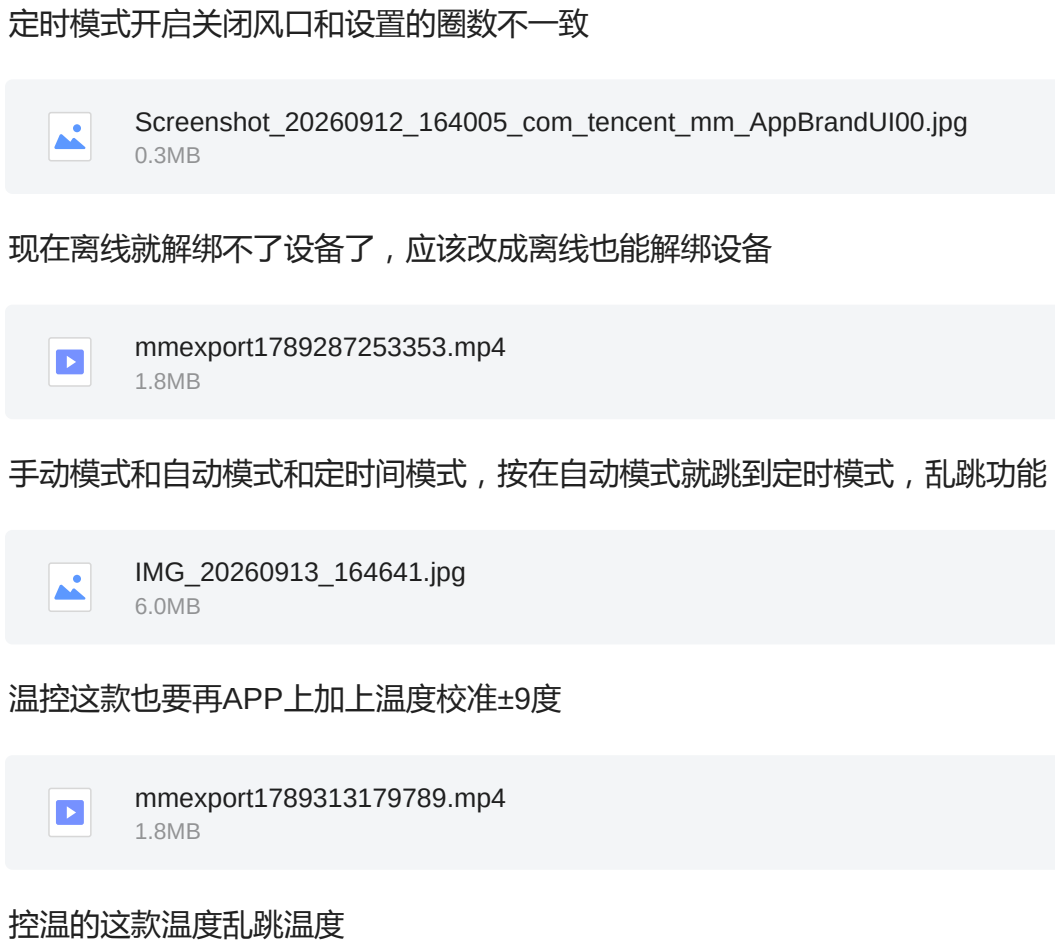
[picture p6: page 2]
Screenshot_20260912_164005_com_tencent_mm_AppBrandUI00.jpg 0.3MB; mmexport1789287253353.mp4 1.8MB; IMG_20260913_164641.jpg 6.0MB; 温控这款也要再APP上加上温度校准±9度; mmexport1789313179789.mp4 1.8MB; 控温的这款温度乱跳温度

手动模式和自动模式和定时间模式，按在自动模式就跳到定时模式，乱跳功能

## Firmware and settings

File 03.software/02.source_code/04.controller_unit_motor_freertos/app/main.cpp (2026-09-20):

#include "FreeRTOS.h"
#include "task.h"
#include "console_logger.h"
#include "config.hpp"
#include "env.hpp"
#include "gui.hpp"
#include "lte_service.hpp"
#include "iot_service.hpp"
#include "ventilate_service.hpp"
#include "systimer.hpp"
#include "py32f071_hal_cortex.h"

/* Main 周期 100ms；GUI 心跳停满该拍数则软复位. */
#define GUI_HEARTBEAT_STALL_LOOPS 100u /* 10s */

int main(){
    /* 系统初始化序列. */

    /* 初始化系统定时器. */
    if ( SysTimer::init() != true ){
        LOG_ERROR("Systimer init failed.");
        return -1;
    }else{
        LOG_INFO("Systimer init complete.");
    }

    /* 初始化配置. */
    if ( ConfigService::init() != true ){
        LOG_ERROR("Config service init failed.");
        return -1;
    }else{
        LOG_INFO("Config service init complete.");
    }

    /* 初始化环境监测服务. */
    if ( Env::init() != true ){
        LOG_ERROR("Env service init failed.");
        return -1;
    }else{
        LOG_INFO("Env service init complete.");
    }

    /* 初始化图形界面服务. */
    if ( GUI::init() != true ){
        LOG_ERROR("GUI init failed.");
        return -1;
    }else{
        LOG_INFO("GUI init complete.");
    }

    /* 初始化LTE服务. */
    if ( LTEService::init() != true ){
        LOG_ERROR("LTE service init failed.");
        return -1;
    }else{
        LOG_INFO("LTE service init complete.");
    }

    /* 初始化通风控制服务. */
    if ( VentilateService::init() != true ){
        LOG_ERROR("Ventilate service init failed.");
        return -1;
    }else{
        LOG_INFO("Ventilate service init complete.");
    }

    /* 初始化IOT服务. */
    if ( IOTService::init() != true ){
        LOG_ERROR("IOT service init failed.");
        return -1;
    }else{
        LOG_INFO("IOT service init complete.");
    }

    LOG_INFO("System init complete.");

    /* 启动服务：IOT 先建，堆只剩约 1KB 时后建会失败导致无法联网. */
    if ( IOTService::start() != true ){
        LOG_ERROR("IOT service start failed.");
    }

    if ( GUI::start() != true ){
        LOG_ERROR("GUI service start failed.");
        return -2;
    }

    if ( Env::start() != true ){
        LOG_ERROR("Env service start failed.");
        return -2;
    }

    size_t free_heap_size = xPortGetFreeHeapSize();

    LOG_INFO("System startup complete.");
    LOG_INFO("Free Heap Size: %d.", free_heap_size);

    unsigned int last_gui_hb = GUI::heartbeat_tick();
    unsigned int gui_stall_loops = 0;
    bool gui_hb_seen = false;

    while ( true ){
        /* 先电机后采样：避免 AHT 忙等拖住本拍驱动. */
        VentilateService::eventloop();
        Env::eventloop();

        /* GUI 刷屏心跳：首次见到后再计时，停满 10s 停电机并软复位. */
        {
            unsigned int hb = GUI::heartbeat_tick();
            if ( hb != last_gui_hb ){
                last_gui_hb = hb;
                gui_stall_loops = 0;
                gui_hb_seen = true;
            }else if ( gui_hb_seen ){
                gui_stall_loops++;
                if ( gui_stall_loops >= GUI_HEARTBEAT_STALL_LOOPS ){
                    LOG_ERROR("GUI heartbeat stall 10s, soft reset.");
                    VentilateService::force(VentilateService::ForceAction::None);
                    vTaskDelay(pdMS_TO_TICKS(50));
                    HAL_NVIC_SystemReset();
                }
            }
        }

        vTaskDelay(pdMS_TO_TICKS(100));
    }
    return 0;
}

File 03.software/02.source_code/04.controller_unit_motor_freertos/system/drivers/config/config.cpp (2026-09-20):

#include "config.hpp"
#include "py32f071_hal_rcc.h"
#include "py32f071_hal_flash.h"
#include "py32f071_hal_cortex.h"
#include "cstdint"
#include "console_logger.h"
#include <cstring>
#include "FreeRTOS.h"
#include "task.h"
#include "semphr.h"

typedef struct StorageBlock {
    char magic_number[4];
    int index;
    Config_t config;
} StorageBlock_t;

static const char MAGIC_NUMBER[4] = {'C','F','3',0};
static const char MAGIC_NUMBER_LEGACY[4] = {'C','F','2',0};
static Config_t system_config;
static volatile bool store_dirty = false;
static SemaphoreHandle_t hw_mutex = nullptr;

static void hw_lock(void){
    if ( (hw_mutex != nullptr) && (xTaskGetSchedulerState() != taskSCHEDULER_NOT_STARTED) ){
        xSemaphoreTake(hw_mutex, portMAX_DELAY);
    }
}

static void hw_unlock(void){
    if ( (hw_mutex != nullptr) && (xTaskGetSchedulerState() != taskSCHEDULER_NOT_STARTED) ){
        xSemaphoreGive(hw_mutex);
    }
}

bool ConfigService::lock_hw(void){
    hw_lock();
    return true;
}

bool ConfigService::try_lock_hw(void){
    if ( (hw_mutex == nullptr) || (xTaskGetSchedulerState() == taskSCHEDULER_NOT_STARTED) ){
        return true;
    }
    return (xSemaphoreTake(hw_mutex, 0) == pdTRUE);
}

bool ConfigService::unlock_hw(void){
    hw_unlock();
    return true;
}
static const Config_t default_system_config = {
    .temp_alert_upper_limit = 450,
    .temp_alert_lower_limit = 100,
    .temp_control_mode = TempControlMode_Limit,
    .target_central_temp = 250,
    .temp_return_diff_positive = 0,
    .temp_return_diff_negative = 0,
    .temp_compensation_value = 0,
    .ventilator_timing_config = {
        [0] = {
            .time = 9,
            .opening_percentage = 50,
        },
        [1] = {
            .time = 11,
            .opening_percentage = 100,
        },
        [2] = {
            .time = 16,
            .opening_percentage = 50,
        },
        [3] = {
            .time = 17,
            .opening_percentage = 0,
        },
    },
    .motor_stroke_time = 3, /* 默认 3 圈. */
    .data_upload_interval = 5,
    .local_alarm_switch = 1,
    .working_mode = WorkingMode::WorkingMode_Manual,
    .device_valid = 1,
    .last_opening_percentage = 0,
    .temp_vent_upper_limit = 250, /* P5 默认 25.0℃（×10）. */
    .temp_vent_lower_limit = 200, /* P6 默认 20.0℃（×10）. */
    .motor_turn_seconds = MOTOR_TURN_SECONDS_DEFAULT, /* C2 默认 25 秒/圈. */
    .last_motor_timer_cnt = 0,
};

#define STORAGE_BLOCK_SIZE sizeof(StorageBlock_t)

#define PAGE_SIZE 512

static void clamp_turn_seconds(Config_t &config){
    if ( (config.motor_turn_seconds < MOTOR_TURN_SECONDS_MIN)
         || (config.motor_turn_seconds > MOTOR_TURN_SECONDS_MAX) ){
        config.motor_turn_seconds = MOTOR_TURN_SECONDS_DEFAULT;
    }
}

static void clamp_stroke_time(Config_t &config){
    clamp_turn_seconds(config);
    /* 旧固件曾把 C1 存成秒(常见 30~300)。若明显偏大且像“秒”而非圈数，按 C2 换算.
     * 协议圈数上限 999；超过 999 一律钳到最大. */
    if ( config.motor_stroke_time > MOTOR_STROKE_TURNS_MAX ){
        config.motor_stroke_time = MOTOR_STROKE_TURNS_MAX;
    }else if ( config.motor_stroke_time < MOTOR_STROKE_TURNS_MIN ){
        config.motor_stroke_time = MOTOR_STROKE_TURNS_MIN;
    }
}

/* 回差只允许 0-5℃ 整数，内部按 0.1℃ 存储. */
static void clamp_hysteresis(Config_t &config){
    int pos = config.temp_return_diff_positive / 10;
    int neg = config.temp_return_diff_negative / 10;
    if ( pos < 0 ){
        pos = 0;
    }else if ( pos > 5 ){
        pos = 5;
    }
    if ( neg < 0 ){
        neg = 0;
    }else if ( neg > 5 ){
        neg = 5;
    }
    config.temp_return_diff_positive = pos * 10;
    config.temp_return_diff_negative = neg * 10;
}

/* P4 温度补偿/校准：−9.0～+9.0℃（内部 ×10）. */
static void clamp_temp_compensation(Config_t &config){
    if ( config.temp_compensation_value < -90 ){
        config.temp_compensation_value = -90;
    }else if ( config.temp_compensation_value > 90 ){
        config.temp_compensation_value = 90;
    }
}

/* S0 数据上报间隔：5-30 秒，写入 Flash. */
static void clamp_upload_interval(Config_t &config){
    if ( config.data_upload_interval < DATA_UPLOAD_INTERVAL_MIN ){
        config.data_upload_interval = DATA_UPLOAD_INTERVAL_MIN;
    }else if ( config.data_upload_interval > DATA_UPLOAD_INTERVAL_MAX ){
        config.data_upload_interval = DATA_UPLOAD_INTERVAL_MAX;
    }
}
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

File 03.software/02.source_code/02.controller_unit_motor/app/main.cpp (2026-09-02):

#include "console_service.hpp"
#include "lte_service.hpp"
#include "gui.hpp"
#include "env.hpp"
#include "config.hpp"
#include "systimer.hpp"
#include "ventilate_service.hpp"
#include "iot_service.hpp"

extern "C"
int main(){
    if ( ConsoleService::init() ){
        LOG_INFO("Console Service init complete.");
    }
    SysTimer::init();
    ConfigService::init();
    Env::init();
    GUI::init();
    LTEService::init();
    VentilateService::init();
    IOTService::init();

    LOG_INFO("System init complete.");

    SysTimer::regist_task(VentilateService::eventloop,100);
    SysTimer::regist_task(GUI::eventloop,100);
    SysTimer::regist_task(GUI::indev_eventloop,1);
    SysTimer::regist_task(Env::eventloop,500);
    SysTimer::regist_task(IOTService::eventloop,2000);
    while ( true ){
        SysTimer::eventloop();
    }
}

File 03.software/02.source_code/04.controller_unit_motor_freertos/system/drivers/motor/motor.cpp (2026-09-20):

#include "motor.hpp"
#include "console_logger.h"

#define MOTOR_LIMIT_IGNORE_TICKS 10
#define MOTOR_LIMIT_CONFIRM_TICKS 8
#define MOTOR_BASELINE_TICKS 5
#define MOTOR_STALL_CONFIRM_TICKS 6
#define MOTOR_STALL_RATIO 1.2
#define MOTOR_STALL_DELTA 0.15

Motor::Motor(PortableStrategy &portable_strategy,Parameter param) : portable_strategy(portable_strategy), param(param) {
    this->state = State::IDLE;
    this->current = 0.0;
    this->limit_ignore_cnt = 0;
    this->home_seek = false;
    this->calibrating = false;
    this->ignore_stall = false;
    this->ignore_zero_current = false;
    this->reset_motion_detect();
}

void Motor::reset_motion_detect(void){
    this->stop_cnt = 0;
    this->oc_cnt = 0;
    this->stall_cnt = 0;
    this->baseline_cnt = 0;
    this->run_current = 0.0;
    this->run_current_ready = false;
}

bool Motor::init(){
    return this->portable_strategy.init();
}

bool Motor::deinit(){
    return this->portable_strategy.deinit();
}

bool Motor::execute_action(Action action){
    switch ( action ){
        case Action::FORWARD: {
            this->portable_strategy.set_output(PortableStrategy::Pin::REVERSE,false);
            this->portable_strategy.set_output(PortableStrategy::Pin::FORWARD,true);
            this->reset_motion_detect();
            this->limit_ignore_cnt = MOTOR_LIMIT_IGNORE_TICKS;
            this->state = State::RUNNING_FORWARD;
            break;
        }
        case Action::REVERSE: {
            this->portable_strategy.set_output(PortableStrategy::Pin::FORWARD,false);
            this->portable_strategy.set_output(PortableStrategy::Pin::REVERSE,true);
            this->reset_motion_detect();
            this->limit_ignore_cnt = MOTOR_LIMIT_IGNORE_TICKS;
            this->state = State::RUNNING_REVERSE;
            break;
        }
        default: {
            this->portable_strategy.set_output(PortableStrategy::Pin::FORWARD,false);
            this->portable_strategy.set_output(PortableStrategy::Pin::REVERSE,false);
            this->reset_motion_detect();
            this->state = State::IDLE;
            break;
        }
    }
    return true;
}

bool Motor::get_state(State &value){
    value = this->state;
    return true;
}

bool Motor::get_current(double &value){
    value = this->current;
    return true;
}

void Motor::eventloop(){
    uint16_t adc_value = 0;
    if ( this->portable_strategy.get_adc_value(adc_value) != true ){
        return;
    }

    if ( this->limit_ignore_cnt > 0 ){
        this->limit_ignore_cnt--;
    }

    double current = ((double)adc_value) * this->param.cs_k + this->param.cs_b;
    if ( (this->state == State::RUNNING_REVERSE) && (this->timer_cnt <= 0)
         && (this->home_seek == false) && (this->calibrating == false) ){
        this->timer_cnt = 0;
        this->execute_action(Motor::Action::STOP);
        this->current = current;
        return;
    }
    /* Overcurrent stop disabled: do not trip ERROR_OVC. */
    this->oc_cnt = 0;
    if ( current < this->param.zero_threshold ){
        if ( this->home_seek || this->ignore_zero_current ){
            /* 寻限位：假零流不停，等堵转或上层确认. */
            this->stop_cnt = 0;
        }else if ( this->ignore_stall ){
            /* 定点/强制行程中途：忽略假零流，避免反复停机把调度/日志打爆、屏停住. */
            this->stop_cnt = 0;
        }else if ( this->limit_ignore_cnt > 0 ){
            this->stop_cnt = 0;
        }else if ( stop_cnt < MOTOR_LIMIT_CONFIRM_TICKS ){
            stop_cnt++;
        }else{
            stop_cnt = 0;
            if ( (this->state == State::RUNNING_FORWARD) || (this->state == State::RUNNING_REVERSE) ){
                LOG_INFO("Motor current limit, stop.");
                this->execute_action(Motor::Action::STOP);
                this->state = State::IDLE;
            }
        }
    }else{
        this->stop_cnt = 0;
        /* home_seek 只放开软件 0 停转，不屏蔽堵转（否则关/开到机械限位永远不停）. */
        if ( this->calibrating || this->ignore_stall ){
            this->stall_cnt = 0;
        }else if ( this->limit_ignore_cnt > 0 ){
            this->stall_cnt = 0;
        }else if ( (this->state == State::RUNNING_FORWARD) || (this->state == State::RUNNING_REVERSE) ){
            if ( this->run_current_ready == false ){
                this->run_current += current;
                this->baseline_cnt++;
                if ( this->baseline_cnt >= MOTOR_BASELINE_TICKS ){
                    this->run_current = this->run_current / (double)MOTOR_BASELINE_TICKS;
                    this->run_current_ready = true;
                    this->stall_cnt = 0;
                }
            }else{
                double trip = this->run_current * MOTOR_STALL_RATIO;
                if ( trip < (this->run_current + MOTOR_STALL_DELTA) ){
                    trip = this->run_current + MOTOR_STALL_DELTA;
                }
                if ( current >= trip ){
                    this->stall_cnt++;
                    if ( this->stall_cnt >= MOTOR_STALL_CONFIRM_TICKS ){
                        this->stall_cnt = 0;
                        LOG_INFO("Motor stall, stop.");
                        this->execute_action(Motor::Action::STOP);
                        this->state = State::IDLE;
                    }
                }else{
                    this->stall_cnt = 0;
                    if ( current < this->run_current ){
                        this->run_current = this->run_current * 0.9 + current * 0.1;
                    }
                }
            }
        }
    }
    this->current = current;
}

void Motor::timer_trigger(void){
    if ( this->calibrating ){
        /* 校准往返都累计时间，反向时不能按开度倒计时. */
        if ( (this->state == State::RUNNING_FORWARD) || (this->state == State::RUNNING_REVERSE) ){
            this->timer_cnt += 1;
        }
        return;
    }
    if ( this->state == State::RUNNING_FORWARD ){
        this->timer_cnt += 1;
    }else if ( this->state == State::RUNNING_REVERSE ){
        if ( this->timer_cnt > 0 ){
            this->timer_cnt -= 1;
        }
        if ( (this->timer_cnt <= 0) && (this->home_seek == false) ){
            this->timer_cnt = 0;
            this->execute_action(Motor::Action::STOP);
        }
    }
}

bool Motor::reset_timer(void){
    this->timer_cnt = 0;
    return true;
}

bool Motor::get_timer_cnt(int64_t &cnt){
    cnt = this->timer_cnt;
    return true;
}

bool Motor::set_timer_cnt(int64_t cnt){
    this->timer_cnt = cnt;
    return true;
}

void Motor::set_home_seek(bool enable){
    this->home_seek = enable;
}

void Motor::set_calibrating(bool enable){
    this->calibrating = enable;
}

void Motor::set_ignore_stall(bool enable){
    this->ignore_stall = enable;
    if ( enable ){
        this->stall_cnt = 0;
    }
}

void Motor::set_ignore_zero_current(bool enable){
    this->ignore_zero_current = enable;
    if ( enable ){
        this->stop_cnt = 0;
    }
}

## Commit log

2026-09-02 Add firmware sources and docs: NTC/ADC sensor fixes, mode-change opening hold, FreeRTOS motor/sensor controllers.
    [JLW-T15606PW.dwg]
2026-09-14 Update FreeRTOS motor/sensor firmware: auto vent on mode enter, MQTT temp calibration (±9°C), and flash tooling.
2026-09-20 Improve motor end-stop: stall (3s ~0A) or 0%/100%, then IDLE 5s arrive; MQTT gate until connected.
    [config.cpp, main.cpp, motor.cpp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]
2026-09-20 Refine end-stop: full open stops at C1xC2 with no overshoot; close 0% overshoots 1s; IDLE 5s only on stall.
